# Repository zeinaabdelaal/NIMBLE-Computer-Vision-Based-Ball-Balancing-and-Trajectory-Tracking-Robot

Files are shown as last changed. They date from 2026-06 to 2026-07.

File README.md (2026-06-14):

# NIMBLE: Computer Vision Based Ball Balancing & Trajectory Tracking Robot

### System setup
<br>

f4afa68b-89f5-4ad4-aba0-d910d50fece1  

<br>
<br>

### Robot assembly
<br>

  

<br>
<br>

### Functional diagram 
<br>

ChatGPT Image May 22, 2026, 03_35_27 PM  

<br>
<br>

NIMBLE is a full-stack mechatronics system combining computer vision, embedded real-time control, inverse kinematics, and mechanical design into a single cohesive robot. A webcam detects the ball's position in real time, a Python application computes the positional error, and an STM32 microcontroller runs dual independent PID controllers that command two stepper motors to tilt a platform and keep the ball exactly where you want it.

Beyond simple balancing, the system supports trajectory tracking — the ball can follow a circle, a figure-eight, or any freehand path you sketch in the GUI.

Developed as a final project for Mechatronics Engineering (MCTR601) at the German University in Cairo.  
Supervised by Prof. Ayman A. El-Badawy.

This repository contains full documentation of the project and all CAD, lasercuting and code files.

Contributers:  
Zeina Abdelaal, Farah Abdelaal, Ahmed Shawki

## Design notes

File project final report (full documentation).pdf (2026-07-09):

## Mechatronics Engineering (MCTR601)

## Project Final Report

NIMBLE: Computer Vision Based Ball Balancing & Trajectory Tracking Robot

Name | ID | Lab Number
Zeina Abdelaal | 61-9589 | T-36
Ahmed Shawki | 61-32383 | T-35
Farah Abdelaal | 61-9586 | T-35

Supervised By:
Prof. Ayman A. El-Badawy

### Table of Contents

1. Project Description
2. Methodology
Mechanical design
Electrical design
3. Control
Modeling
Analysis
Controller Design
4. Programming
Computer Vision & GUI
STM32 Firmware (FreeRTOS)
5. Upgrades

### Project Description

Overview

The project is a vision-based ball balancing robot that keeps a ball at the center of a 2-DOF tilting platform using camera feedback and closed-loop control. The system combines computer vision, embedded control, inverse kinematics and mechanical design to continuously detect the ball’s position and adjust the platform angle to stabilize it. The challenge requires sensing the ball position in real time, computing corrective tilt angles, and actuating them fast enough to reject disturbances and maintain balance.

In addition to stabilization, the system also supports trajectory tracking, where the ball can be guided along predefined paths, such as a circular/infinity sign trajectory or a custom freehand sketch. This is achieved by dynamically updating the target position used to calculate the error, allowing the robot to not only balance the ball but also control its motion smoothly across the platform.

To enhance user interaction, the system includes a graphical user interface (GUI) for mode selection and trajectory drawing. It allows switching between different operating modes in real time, including center balancing mode, predefined trajectory tracking mode, and custom freehand drawing mode. Also enabling the user to sketch and edit the custom paths that the ball will follow on the platform.

How the System Works

A webcam captures images of the platform and detects the position of the ball (x,y) using image processing techniques (OpenCV running on a PC). The ball’s x and y positional errors relative to the desired target setpoint are then computed and sent to the STM32 through serial communication.

The STM32 runs two independent PID control algorithms that calculate how much the platform should tilt in the x and y directions to move the ball toward the target position. Based on this calculation, the microcontroller commands two stepper motors that adjust the platform angle.

The platform is supported using a central mount and 2 robotic arms that are built using custom 3D-printed links and mechanical components, creating a stable structure that allows controlled tilting in two axes.

Through this continuous loop — camera detection → position calculation → PID control → motor adjustment — the robot maintains the ball balanced at the center of the platform in real time.

Components Used

Sensor:
The primary sensor is the overhead USB webcam running at 30fps, which provides the (x, y) position of the ball through OpenCV-based image processing on the host PC.

Actuators:
Two Nema 17 stepper motors driven by their dedicated motor drivers (A4988); each motor controls tilt about one of the two platform axes (X & Y).

Microcontroller:

STM32 Blue Pill, acts as the real-time control unit, receives and parses the ball’s positional error transmitted over USART, executes the PID loops and generates the required stepper step/direction signals accordingly.

Communication Protocol:
A USB-to-TTL converter is used as the communication interface between the computer and the STM32. It transmits the ball’s positional error (x,y), over serial communication (USART) to the STM32.

Power Supply:

Two 12V 2A adaptors to power both motors.

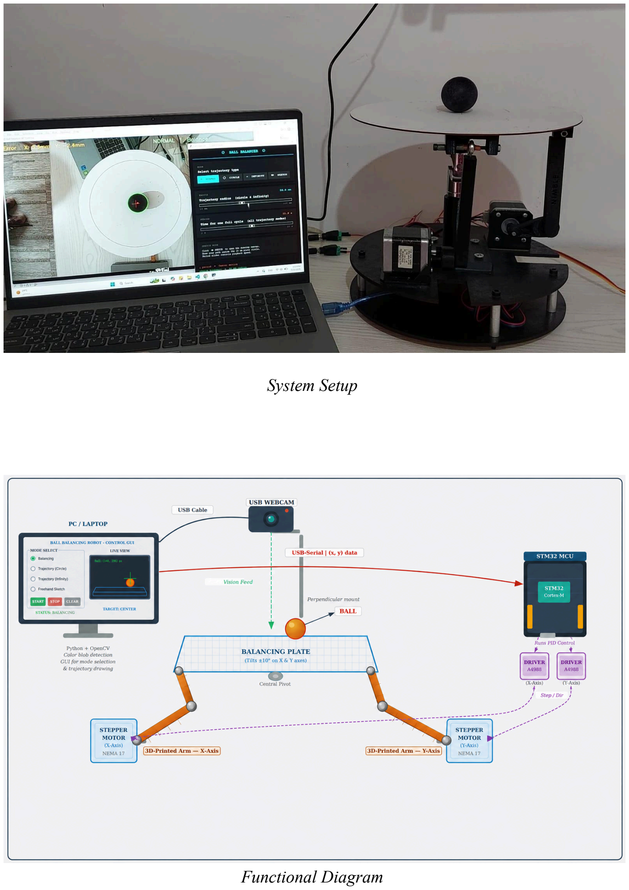
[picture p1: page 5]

System Setup

Functional Diagram

### Methodology

### 1. Mechanical design

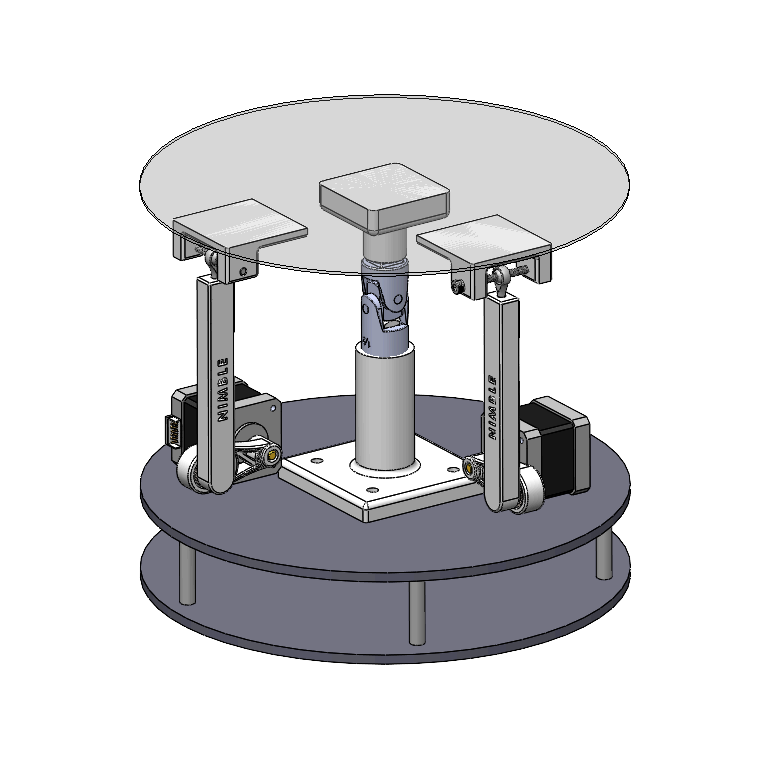
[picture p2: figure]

Robot Solidworks Assembly

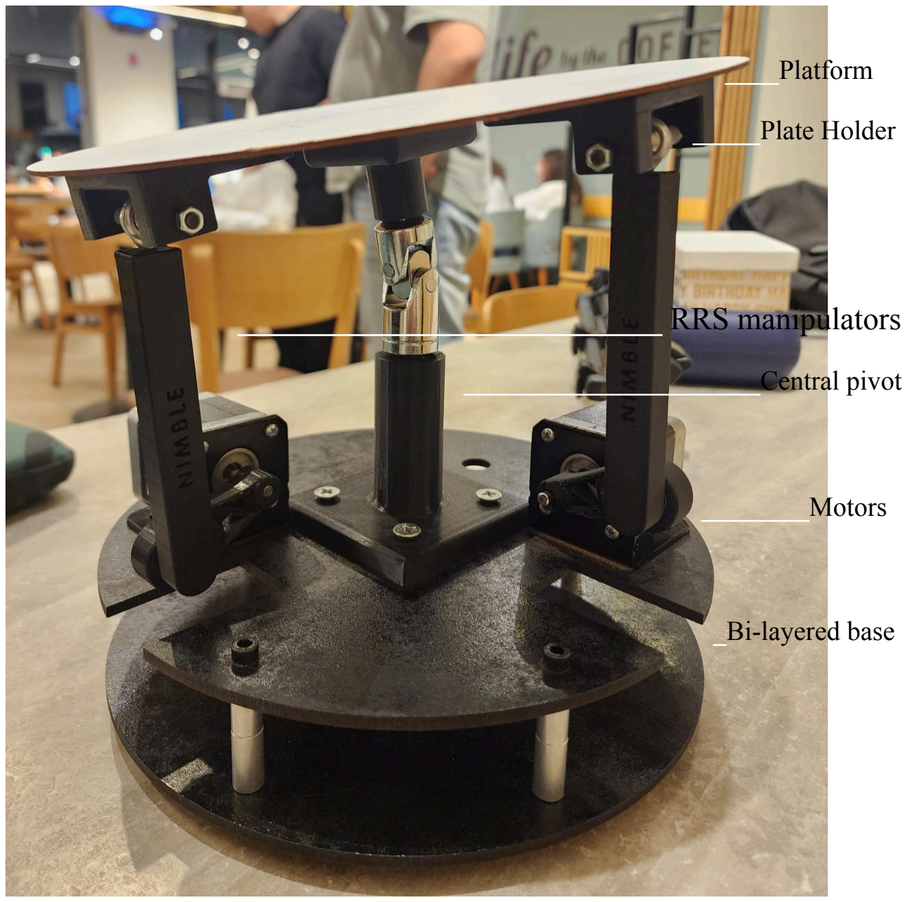
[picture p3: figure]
____Platform; _____Plate Holder; ______________________Central pivot; ________Motors; _Bi-layered base

___________________________ RRS manipulators

Real life Hardware with key components labelled

RRS Parallel Manipulators Design

We designed two RRS (Revolute-Revolute-Spherical) manipulators, each driven by a stepper motor to control platform tilt along one axis independently.

Each leg consists of two rigid links, a short arm and a long arm, connected in series by three joints

Starting from the base, the short arm is press-fitted directly onto the stepper motor shaft, forming the first actuated revolute joint - a clean rotational connection driven by the motor itself.

The long arm is then connected to the short arm via a 688ZZ bearing, forming the second revolute joint and allowing the long arm to rotate relative to the short arm about a single fixed axis.

At the top of the long arm, an M4 spherical joint connects to the plate holder, forming the terminal spherical joint. This allows rotation about multiple axes, accommodating the platform's combined tilt from both legs simultaneously. The plate holder is fastened via an M4 bolt, anchoring the platform while permitting free orientation in response to the manipulators' motion.

Together, the two decoupled RRS legs produce a 2-DOF tilting platform, with each leg independently controlling tilt about one axis.

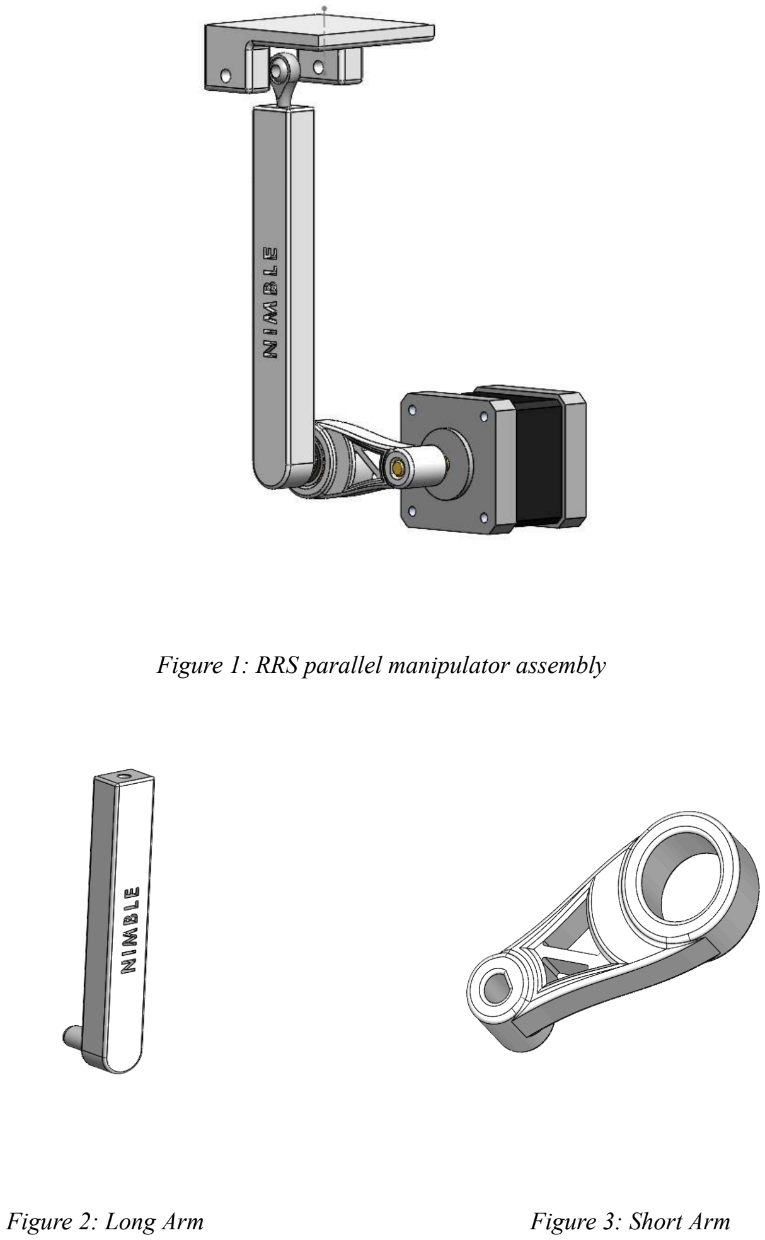
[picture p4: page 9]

Figure 1: RRS parallel manipulator assembly

Figure 2: Long Arm | Figure 3: Short Arm

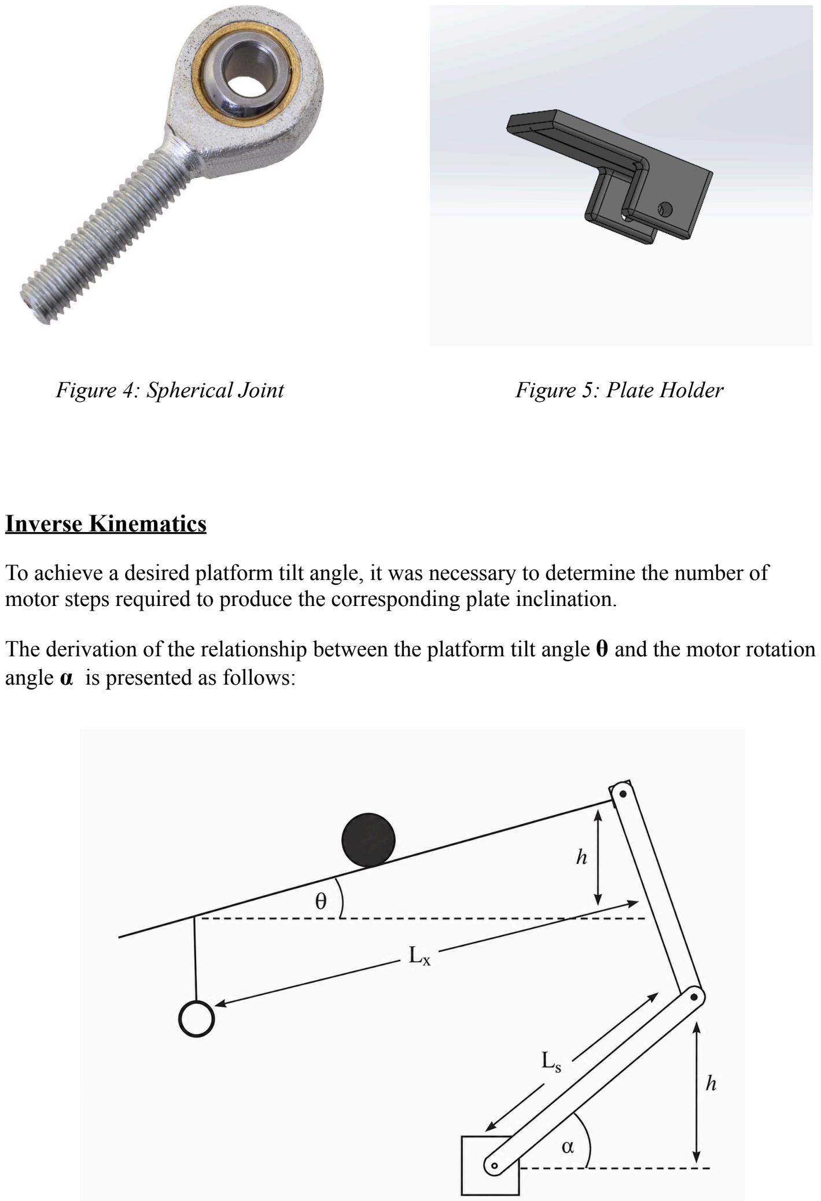
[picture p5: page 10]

Figure 4: Spherical Joint | Figure 5: Plate Holder

Inverse Kinematics

To achieve a desired platform tilt angle, it was necessary to determine the number of motor steps required to produce the corresponding plate inclination.

The derivation of the relationship between the platform tilt angle θ and the motor rotation angle α is presented as follows:

For simplicity and due to the small range of motion the long arm is assumed to be vertical throughout the motion. It therefore transmits vertical displacement directly and without distortion from the crank tip to the plate attachment point. This gives the central assumption:

h_{short arm} = h_{plate}

Left side — vertical height of the short arm tip above the motor pivot:

h_{short arm} = Ls sin(α)

Right side — vertical height of the plate attachment point, at distance Lx along the plate tilted by θ:

h_{plate} = Lx sin(θ)

Setting equal:

Ls sin(α) = Lx sin(θ)

Solving directly for the motor angle:

α=arcsin (Lx/Ls) sin(θ)

Linearized Form (Small Angle Approximation)

applying sinθ≈θ and sinα≈α:

α ≈ Lx/Ls θ

This reveals a constant linear gain (Lx/Ls) between plate angle and motor angle.

The two axes are fully decoupled — αx depends only on θx and αy depends only on θy

The linearized model is suitable for control design in the neighbourhood of the home (flat) position, which is the primary operating region of the manipulator.

For our parameters Lx=10.5cm, Ls=4cm, and ⅛ microstepping, the microsteps per degree of plate tilt is derived as follows.

A standard stepper motor has 200 full steps per revolution. With 1/8 microstepping this gives:

N=200×8=1600 microsteps/revolution

From the linearized IK, the mechanical gain is:

α/θ=Lx/Ls=10.5/4=2.625

meaning each degree of plate tilt demands 2.625° of motor rotation.The number of microsteps per degree of plate tilt is therefore:

microsteps per degree of plate tilt=(1600 * 2.625)/360 = 11.667 microsteps/°

Mount

To support the platform, we designed a central mount that attaches directly to the platform's center. The mount is split into two parts — a top and a bottom — with a Universal Joint sitting between them.

The Universal Joint acts as the core of the mount, linking the two halves while allowing the plate to rotate freely in any direction, giving it full 360° of rotational freedom.

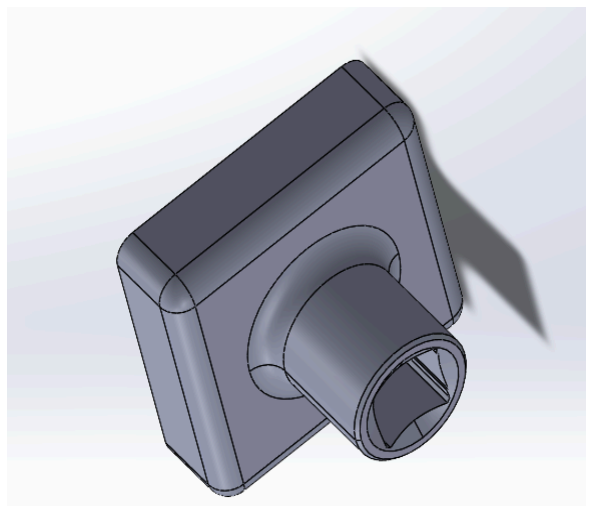
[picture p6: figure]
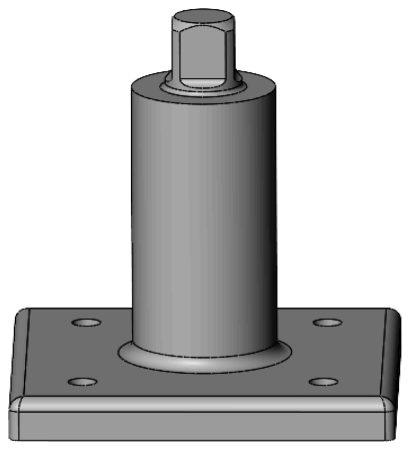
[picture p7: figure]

Figure 6: Top Mount | Figure 7: Bottom Mount

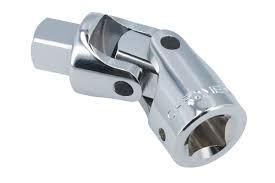
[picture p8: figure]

Figure 8: Universal Joint

Bi-Layered Base

The base consists of two 5mm MDF plates, laser cut for precision and separated by M5 spacers to create a structured two-tier frame.

The top platform houses the stepper motors and the central mount, keeping all mechanical components together in one layer. Cutouts are integrated into the platform, giving the arms the clearance they need to move freely without obstruction.

The bottom platform sits beneath, dedicated to the electrical components, keeping the wiring and electronics neatly separated from the mechanics above.

Platform

The platform was laser cut from 1.5 mm MDF with a diameter of 25 cm , with engravings on its underside marking the precise locations of the central pivot and plate holders. This ensured accurate positioning during assembly.

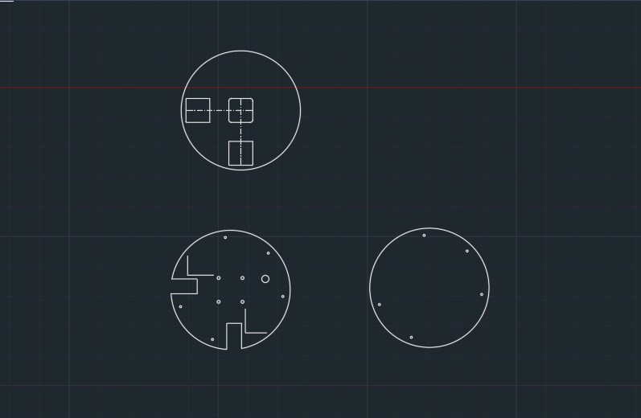
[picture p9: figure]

Figure 9: AutoCAD drawings for laser cutting

### 2.Electrical design

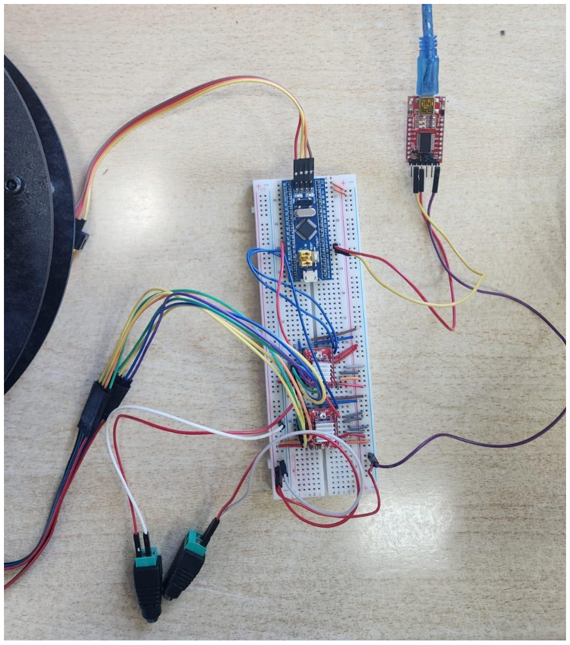
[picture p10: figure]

Components:

- SM32 Blue Pill & ST Link
- USB TTL Converter (To send X,Y positional errors to STM)
- Two A4988 Motor Drivers Connected to two Steppers
- Two 12V adapters (one for each stepper)

### Control

### 1.Modeling

### 1.1 Governing Equations — Derivation and Linearization

The ball balancing system is modelled by analysing the motion of a hollow thin-walled sphere rolling on a tilted plate. The following assumptions are applied:

Assumptions taken:

- The ball rolls without slipping on the plate surface
- Small angle approximation applies: sin(θ) ≈ θ for tilt angles ≤ 8°
- The plate is rigid, flat, and uniform
- Air resistance and rolling friction are neglected
- The two axes (X and Y) are mechanically decoupled and modelled independently
- The ball is a standard ping-pong ball modelled as a hollow thin-walled sphere with moment of inertia I = (2/3)mr²

Equations of motion:

Consider the ball of mass m and radius r rolling on the plate, which is tilted at angle θplate about one axis.

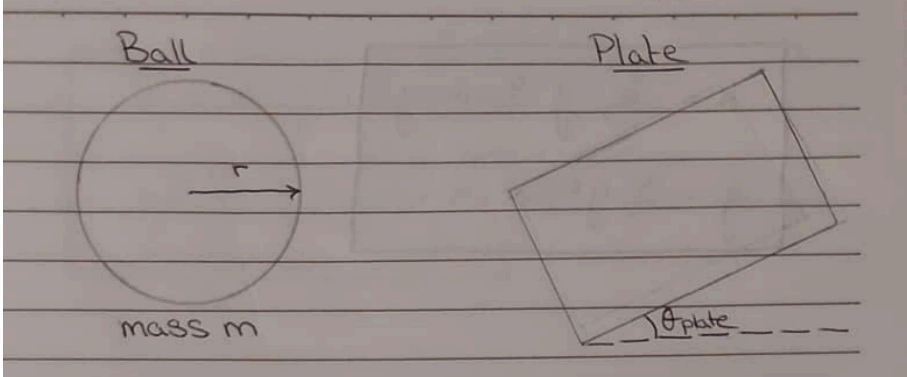
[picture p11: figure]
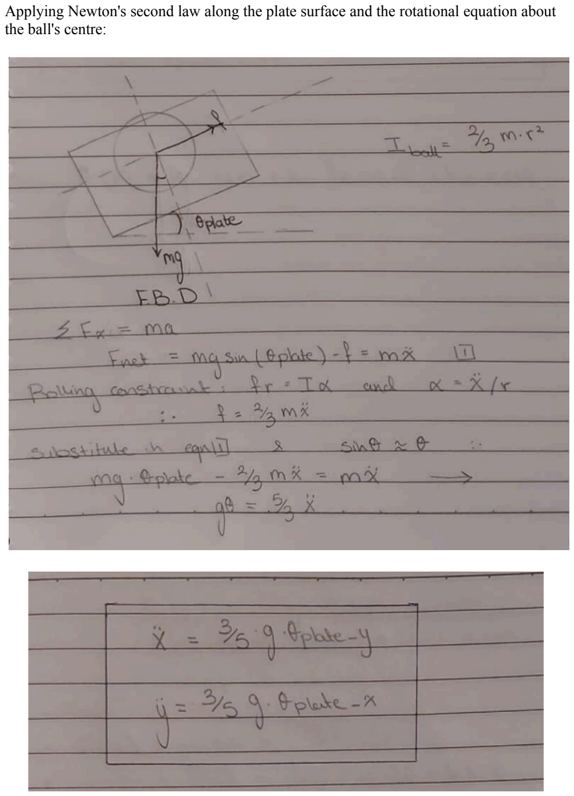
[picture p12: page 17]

Applying Newton's second law along the plate surface and the rotational equation about the ball's centre:

where g = 9.81 m/s² is gravitational acceleration, θplate_x and θplate_y are the plate tilt angles about the X and Y axes respectively, and (3/5) is the rolling inertia factor for a hollow thin-walled sphere. Note that this gives a plant gain of K = (3/5)g = 5.886 m/s²/rad.

### 1.2 Transfer Function Model

Open Loop Transfer Function

Taking the Laplace transform of the equation of motion for a single axis, treating θ_plate

as the control input and ball position x as the output:

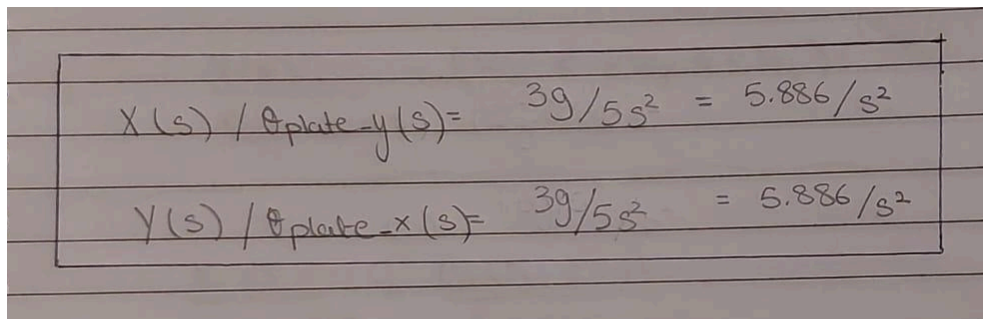
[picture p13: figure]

G(s) = X(s) / Θ_plate(s) = 5.886 /
s²

This is a double integrator plant. It is open-loop unstable with two poles at the origin, which is why active feedback control is required. Both axes share the same transfer function structure, so identical controllers are designed for each axis independently.

The stepper motor is modelled as a first-order lag with time constant τ = 0.0012 s (derived from the hardware step interval of 1200 µs from the C code):

M(s) = 1 / (0.0012s + 1)

The combined plant seen by the PID controller is:

P(s) = M(s) · G(s) = 5.886 / [s² · (0.0012s + 1)]

The open-loop transfer function is:

L_OL(s) = P(s) = 5.886 / [s² · (0.0012s + 1)]

PID Control Law

Each axis is controlled by an independent PID controller of the form:

where:

- e(t) = x_desired − x(t) for the X-axis, or e(t) = y_desired − y(t) for the Y-axis
- θ(t) is the commanded plate tilt angle sent to the stepper motor
- The output is saturated at ±8° matching the physical hardware limit from the STM32 C code

In transfer function form the PID controller is:

C(s) = Kp + Ki/s + Kd·s

Closed Loop Transfer Function

With the PID wrapped around it

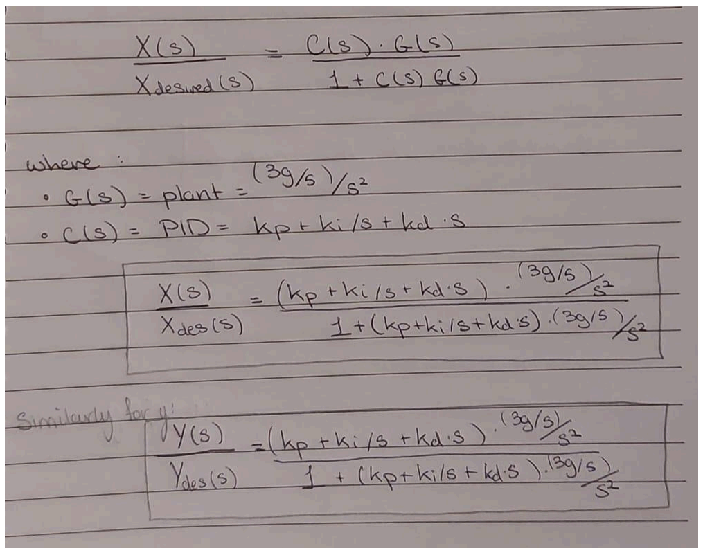
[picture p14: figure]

*Replace G(s) in the photo with P(s) (the combined plant)*

The closed-loop transfer function is:

T(s) = [C(s) · P(s)] / [1 + C(s) · P(s)]

T(s) = [Kp + Ki/s + Kd·s] · 5.886 / [s² · (0.0012s + 1)] -―――――――――――――――――――――――――――――――――――—----------1 + [Kp + Ki/s + Kd·s] · 5.886 / [s² · (0.0012s + 1)]

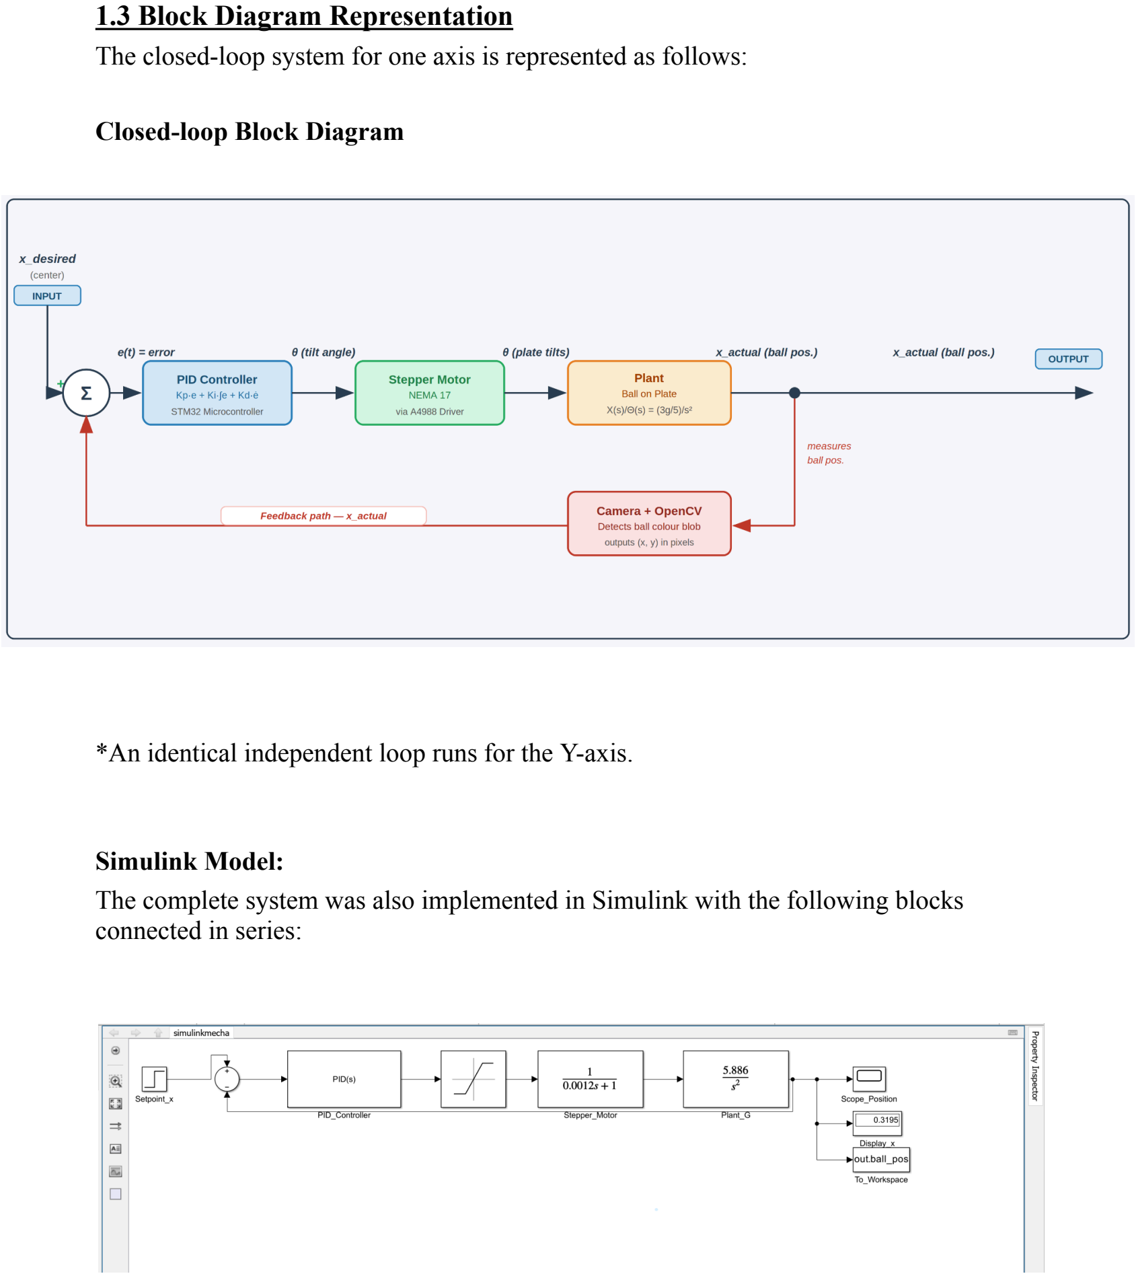
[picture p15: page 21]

### 1.3 Block Diagram Representation

The closed-loop system for one axis is represented as follows:

Closed-loop Block Diagram

*An identical independent loop runs for the Y-axis.

Simulink Model:
The complete system was also implemented in Simulink with the following blocks connected in series:

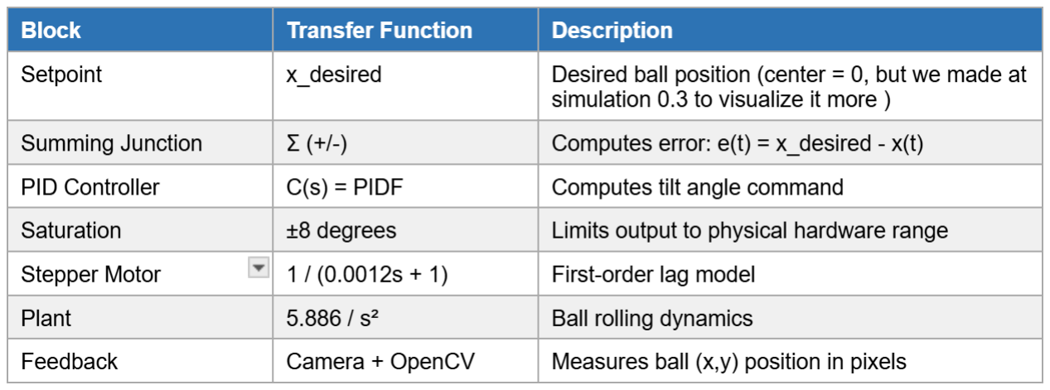
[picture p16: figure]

### 2. Analysis — Open Loop Response

Open-loop poles:

Pole | Location | Meaning
p₁, p₂ | s = 0 (double) | Double integrator — open-loop unstable
p₃ | s = −833 | Stepper motor lag

Open-loop analysis conclusions:

- Two poles at the origin confirm the system is open-loop unstable — any small tilt causes the ball to accelerate indefinitely away from center
- The Bode plot shows a −40 dB/decade slope at low frequencies, characteristic of a double integrator
- The open-loop step response shows ball position diverging to infinity, confirming that active closed-loop control is mandatory

### 3. Controller Design

### 3.1 Controller Design Steps

A PID controller (PID with derivative filter) was selected for the following reasons:

- The double integrator plant requires derivative action to introduce damping
- The integral term eliminates steady-state error as the ball settles at center

- Both X and Y axes use identical independent controllers due to mechanical decoupling

Design procedure:

Step 1 — Define the combined plant including motor dynamics:
P(s) = 5.886 / [s² · (0.0012s + 1)]
Step 2 — Apply MATLAB’s pidtune function targeting the design specifications: opts = pidtuneOptions('CrossoverFrequency', 1.5, 'PhaseMargin', 60) C = pidtune(P, 'PID', opts);
Step 3 — Extracted gains from pid tune output:
Gain | Value | Role
Kp | 0.070303 | Proportional — reacts to current error
Ki | 0.004885 | Integral — eliminates steady-state error
Kd | 0.248320 | Derivative — damps oscillation
Step 4 — Close the loop and verify stability margins and step response (shown in sections below).

### 3.2 Closed-Loop Simulations

The closed-loop system was simulated in MATLAB using the pidtune computed gains with a 33 ms sample time matching the STM32 hardware implementation.

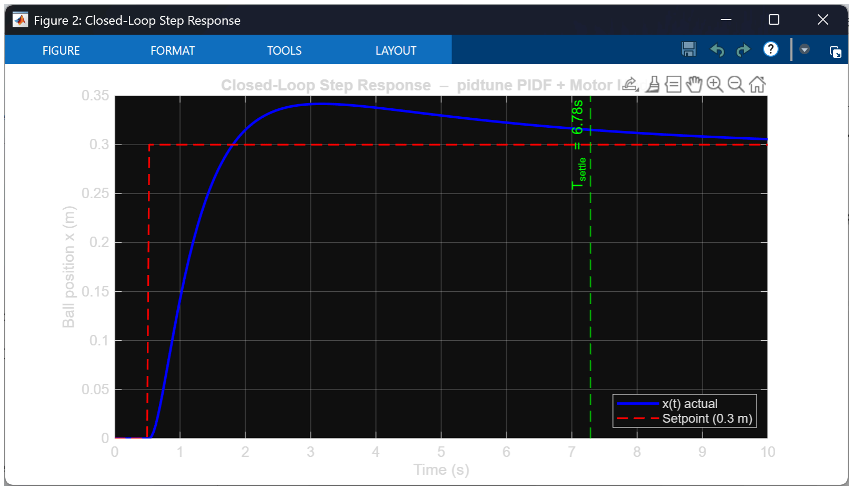
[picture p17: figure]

Closed Loop Step Response

Simulation conditions:
- Setpoint: ball moves from center (0 m) to 0.3 m at t = 0.5 s
- Simulation duration: 10 seconds
- Sample time: 33 ms (from STM32 C code default dt = 0.033 s)
- Output saturation: ±8° (from STM32 C code: output_max = 8.0)

The step response shows the ball position tracking the 0.3 m setpoint successfully. The system is stable with the following performance metrics:

Metric | Value
Settling Time | 6.78 s
Peak Overshoot | ~13% (peak ≈ 0.34 m)
Steady-State Error | ≈ 0 m (integral action eliminates offset)
Setpoint Reached | Yes — ball converges to 0.3 m

Stability Margins (from MATLAB margin function):

Margin | Achieved | Requirement | Status
Phase Margin | ≥ 60° | > 45° | ✓ Pass

Gain Margin | > 6 dB | > 6 dB | ✓ Pass

The closed-loop pole-zero map confirms all poles are located in the left half plane, verifying closed-loop stability.

Note on Comparison with Hardware Implementation
The pidtune computed gains (Kp = 0.070303, Ki = 0.004885, Kd = 0.248320) represent the theoretically optimal values for the specified design targets. The hardware-tuned gains implemented on the STM32 (Kp = 0.06, Ki = 0.02051, Kd = 0.02165) were arrived at through iterative physical testing on the actual robot. The difference between the two sets of gains reflects real-world factors not captured in the mathematical model, including mechanical friction, camera latency, and discrete step resolution of the NEMA 17 stepper motors.

### Programming

### 1. Computer Vision & GUI

The PC-side software is written in Python using OpenCV for real-time ball detection and Tkinter for the control GUI. It runs two concurrent threads — a CV loop processing camera frames at 30 FPS, and a GUI thread that lets the operator switch modes and tune parameters without interrupting tracking.

Computer Vision

Ball Detection Pipeline

Each frame from the USB webcam goes through the following steps:

1. Pre-processing

The raw BGR frame is first blurred with a 5×5 Gaussian kernel to suppress noise, then converted to the HSV colour space. HSV is used instead of BGR because it separates colour (hue) from lighting intensity (value), making the detection robust to changes in ambient light. A colour threshold mask is applied for the black ball:

lower_ball = np.array([0, 0, 0])
upper_ball = np.array([180, 255, 50])

This isolates all pixels with very low brightness (value < 50) regardless of hue, which corresponds to the black ball. The mask is then cleaned up with one erosion pass (removes noise specks) followed by two dilation passes (fills gaps in the ball's silhouette).

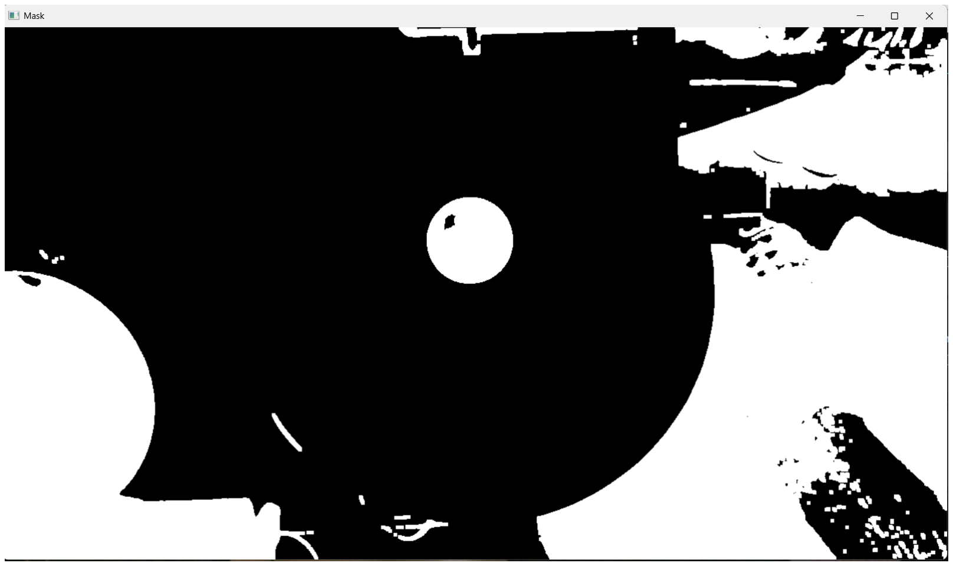
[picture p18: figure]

Masking

2. Contour detection and validation

OpenCV's findContours extracts all connected regions from the binary mask. Each contour is then filtered through two criteria to reject false positives:

- Radius bounds: the minimum enclosing circle must be between a pre-set minimum and maximum radius in pixels (selected based on the physical ball size and the camera height above the platform). This helps reject false detections such as tiny noise blobs or large shadow regions that do not correspond to the ball.

if r < MIN_RADIUS or r > MAX_RADIUS:
continue
- Circularity check: computed as (4π × area) / perimeter², which equals 1.0 for a perfect circle. Only contours with circularity ≥ 0.75 are accepted — rejects non-circular objects like cables or plate edges.

circ = (4 * np.pi * area) / (perim ** 2)
if circ < CIRCULARITY_THRESHOLD:
continue
3. Position extraction and filtering

After validating the contour, the largest valid contour is selected as the ball and its pixel position (ball_x, ball_y) is extracted. An exponential moving average (EMA filter) with α = 0.45 is then applied to reduce jitter from frame-to-frame noise:

x_smooth = 0.45 * ball_x + 0.55 * x_smooth
y_smooth = 0.45 * ball_y + 0.55 * y_smooth

The filtered position is then converted to millimetres relative to the frame centre using a calibrated mm per pixel scale factor (selected based on camera height from platform).

x_smooth_mm = (x_smooth - FRAME_CX) * MM_PER_PIXEL
y_smooth_mm = (y_smooth - FRAME_CY) * MM_PER_PIXEL
5. Error calculation and serial transmission

The smoothed ball coordinate position is compared against the current trajectory setpoint (centre for Normal mode, or a parametric path for Circle/Infinity/Sketch modes). The positional error in mm is multiplied by 10 to send as an integer over UART, avoiding floating point in the serial packet:

error_x_mm = x_smooth_mm - setpoint_x_mm
error_y_mm = y_smooth_mm - setpoint_y_mm
packet = f"<{int(error_x_mm * 10)},{int(error_y_mm * 10)}>\n" stm_serial.write(packet.encode('utf-8'))

The STM32 receives this packet via UART DMA, parses the <x,y> format, and feeds the error directly into the PID controller.

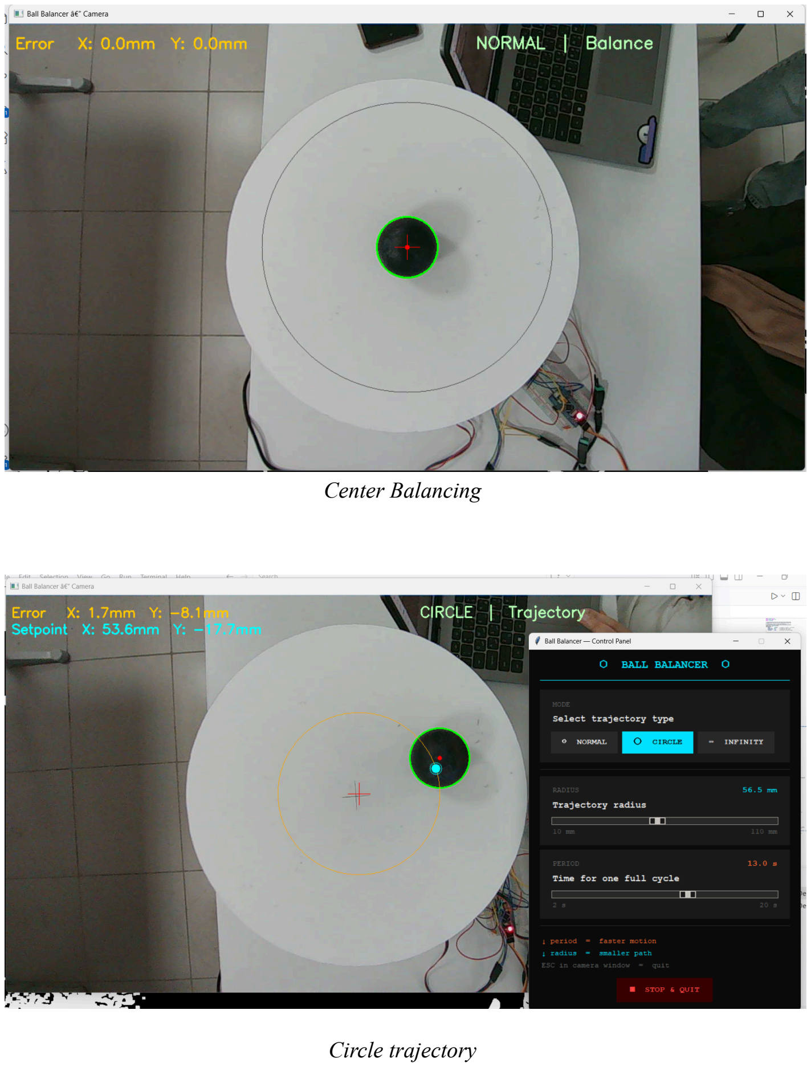
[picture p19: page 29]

Center Balancing

Circle trajectory

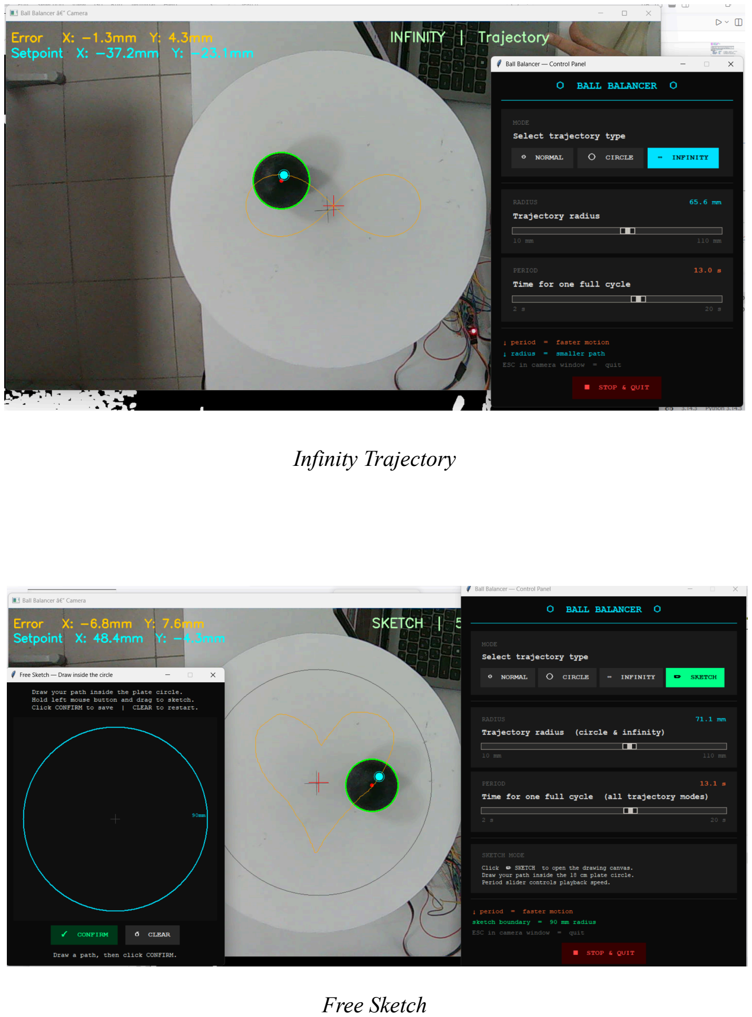
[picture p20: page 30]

Infinity Trajectory

Free Sketch

GUI

The GUI exposes four modes selectable at runtime without restarting the system:

Mode Setpoint behaviour

Normal Fixed at (0, 0) — ball balances at centre

Circle Parametric circle: x = R·cos(ωt), y = R·sin(ωt)

Infinity Lemniscate of Bernoulli (figure-of-eight curve)

Sketch User draws a freehand path on a canvas; ball follows it as a closed loop

The radius (10–110 mm) and period (2–20 s) for the circle and infinity trajectories are adjustable via sliders in real time. In Sketch mode, a drawing canvas appears allowing the user to sketch the desired path. The drawing canvas enforces a 90 mm boundary to reject any out-of-bounds point too close to the plate edge.

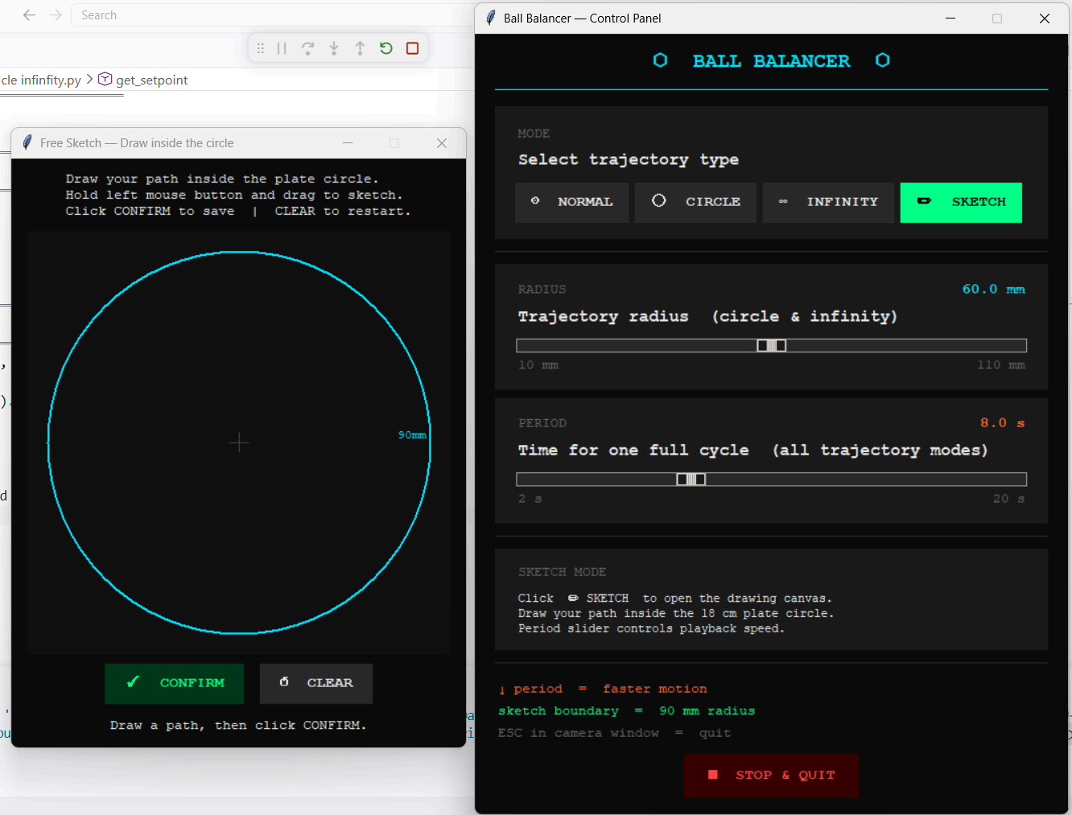
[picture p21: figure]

GUI

### STM32 Firmware (FreeRTOS)

The firmware runs on an STM32F103 at 72 MHz and is structured around FreeRTOS with two cooperative tasks. The PID computation and motor stepping are split into separate tasks that take turns running, while UART reception happens entirely in the background via DMA and an ISR.

System Clock & Timer

The MCU is clocked from an 8 MHz external crystal, multiplied by the PLL to 72 MHz. TIM2 is configured as a free-running microsecond counter:

TIM2->PSC = 71; // 72 MHz ÷ 72 = 1 MHz → 1 tick per µs

TIM2->ARR = 0xFFFFFFFF; // runs continuously, never resets

TIM2->CR1 |= TIM_CR1_CEN;

This 32-bit hardware timestamp is used for both measuring the actual time between PID updates (dt) and enforcing the minimum step interval between motor pulses, replacing all software delay loops for timing.

UART Reception (DMA + IDLE Interrupt)

USART1 runs at 115200 baud and receives packets from the PC in the format <x,y>. DMA Channel 5 is configured to transfer incoming bytes directly into rx_buffer in the background without any CPU involvement:

DMA1_Channel5->CPAR = (uint32_t)&(USART1->DR); // source: UART data register

DMA1_Channel5->CMAR = (uint32_t)rx_buffer; | // destination: rx_buffer
DMA1_Channel5->CNDTR = RX_BUFFER_SIZE; | // up to 32 bytes

The UART IDLE line interrupt fires when the bus goes quiet after a complete packet. The ISR reads how many bytes DMA transferred, null-terminates the buffer, searches for the < start character, and parses the two integers:

uint16_t bytes_received = RX_BUFFER_SIZE - DMA1_Channel5->CNDTR;

sscanf(start, "<%d,%d>", &current_x, &current_y);

new_data_flag = 1;

DMA is then immediately reset to receive the next packet. The ISR only sets a plain volatile flag — no FreeRTOS API calls are made, keeping interrupt latency minimal.

PID Controller

Two independent PID controllers run on the X and Y axes with tuned gains:

pid->kp = 0.06f;

pid->ki = 0.02051f;

pid->kd = 0.02165f;

The derivative term applies a 70/30 low-pass filter to smooth out noise from numerical differentiation:

float raw_derivative = (error - pid->prev_error) / dt;

float derivative = 0.7f * pid->prev_derivative + 0.3f * raw_derivative;

The integral is clamped to ±200 to prevent wind-up, and the output is clamped to ±8° — the physical tilt limit of the plate mechanism. The dt value is the actual elapsed time in seconds between consecutive received packets, measured from TIM2, so the controller adapts automatically if PC frame rate varies.

Stepper Motor Control

Each motor is driven by an A4988 driver over STEP and DIR GPIO pins on GPIOB. Update_Motors() is entirely non-blocking — it reads the current TIM2 timestamp and only pulses the STEP pin if enough time has elapsed since the last step:

if (diff != 0 &&

(now - motor_x.last_step_time_us) >= motor_x.min_step_interval_us) {

motor_x.step_port->BSRR = motor_x.step_pin_mask; // STEP high

delay_us(2); | // 2 µs pulse

motor_x.step_port->BRR = motor_x.step_pin_mask; // STEP low motor_x.current_steps += (diff > 0) ? 1 : -1;

motor_x.last_step_time_us = now;

}

The minimum step interval is 1200 µs, capping speed at ~833 steps/sec. The PID output angle is converted to a step target using 11.66 microsteps per degree of plate tilt (derived from the RRS inverse kinematics above). Direction is set from the sign of the remaining step error before each pulse.

FreeRTOS Task Structure

The firmware uses two tasks at equal priority (2), both calling taskYIELD() to cooperatively hand the CPU to each other:

vPIDTask (priority 2, 512-word stack) — polls new_data_flag on every iteration. When the flag is set by the ISR, it clears it, computes the actual dt, runs both PID controllers, and writes the new step targets to the motor structs. It then calls taskYIELD() to give the motor task a turn:

while (1) {

if (new_data_flag == 1) {

new_data_flag = 0;

// ... compute dt, run PID, update motor targets

}

taskYIELD();

}

vMotorTask (priority 2, 512-word stack) — calls Update_Motors() on every iteration to check whether either motor needs a step pulse, then yields:

while (1) {

Update_Motors();

taskYIELD();

}

Because both tasks are at the same priority and both call taskYIELD(), the FreeRTOS scheduler alternates between them on every yield — effectively running PID check and motor step in a round-robin loop. This mirrors the original bare-metal while(1) structure but separates the two concerns into distinct tasks. Neither task ever blocks or sleeps, since Update_Motors() requires continuous polling of TIM2 to maintain microsecond step timing.

### Upgrades

We later upgraded to a better quality webcam that also features a higher 60fps frame rate. This change required corresponding adjustments in the code to the PID control parameters, derivative filter configuration, and timing constraints to maintain stable and responsive tracking performance at the increased frame rate.

PID Gain Adjustments

The PID gains were recalibrated to account for the reduced time interval between frames. The proportional gain remained unchanged, as it is independent of frame rate. The integral and derivative gains were scaled accordingly.

pid->kp = 0.06f; | // no change (not affected by frame rate)
pid->ki =0.0229712f; | // 1.12 times the 30fps value
pid->kd = 0.01786129f; | // approx 0.825 times the 30fps value

Derivative Filter Update

The smoothing coefficient was adjusted from 70/30 to 80/20, applying stronger filtering to the derivative term to suppress the increased noise sensitivity inherent at shorter sampling intervals.

float derivative = 0.8f * pid->prev_derivative + 0.2f * raw_derivative;

Timing Constraint Adjustment

The upper bound on the time step dt was updated to reflect the expected inter-frame interval at 60 FPS (≈ 16.7 ms)

if (dt > 0.1f || dt <= 0.0f) dt = 0.0167f;

Camera Configuration (OpenCV)

The capture device was explicitly configured to operate at 60 FPS within the computer vision pipeline:

cap.set(cv2.CAP_PROP_FPS, 60)

Note: The actual achieved frame rate is subject to hardware capability. It is recommended to verify the effective frame rate at runtime by printing it in the terminal and confirming it reads 60 FPS.

*All other code remains unchanged from the original 30 FPS implementation.*

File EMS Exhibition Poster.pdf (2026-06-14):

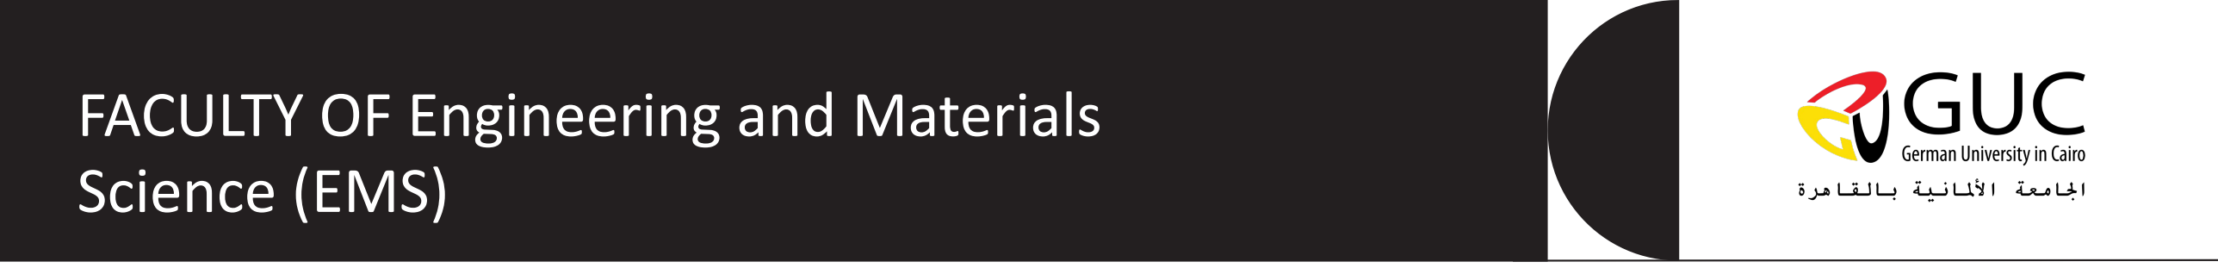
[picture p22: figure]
FACULTY OF Engineering and Materials Science (EMS)

Designed by
Ahmed Shawki, Farah Abdelaal, Zeina Abdelaal

Supervised by
Prof. Ayman A. El-Badawy

# NIMBLE: Computer Vision Based Ball Balancing & Trajectory Tracking Robot

Computer Vision
Using a 30 fps webcam each frame is processed in Python using OpenCV — converted to HSV color space, thresholded to isolate the black ball, and filtered using circularity and radius checks to reject false detections. An exponential moving average filter then smooths the ball's pixel position frame-to-frame, which is compared against the target setpoint to compute the positional error

Overview
NIMBLE is a vision-based ball balancing robot that keeps a ball at the center of a 2-DOF tilting platform using camera feedback and closed-loop control. The system combines computer vision, embedded control, inverse kinematics and mechanical design to continuously detect the ball's position and adjust the platform angle to stabilize it. In addition to stabilization, the system also supports trajectory tracking, where the ball can be guided along predefined paths, such as a circular/infinity sign trajectory or a custom freehand sketch.

Methodology
An overhead webcam captures the ball's positional error using OpenCV image processing and transmits it to an STM32 microcontroller. The STM32 runs two independent PID control loops — one per axis — calculating the required tilt angles. These angles are executed by two NEMA 17 stepper motors, which physically tilt the plate and close the feedback loop.
Trajectory Tracking | Control System Design
| The system models a ping-pong ball on a tilted plate as a double integrator plant G(s) = 5.886/s², making it open-loop unstable. A PID controller stabilizes each axis independently. MATLAB's pidtune achieved ≥60° phase margin and ~6.78s settling time in simulation.

Robot Assembly

Setup

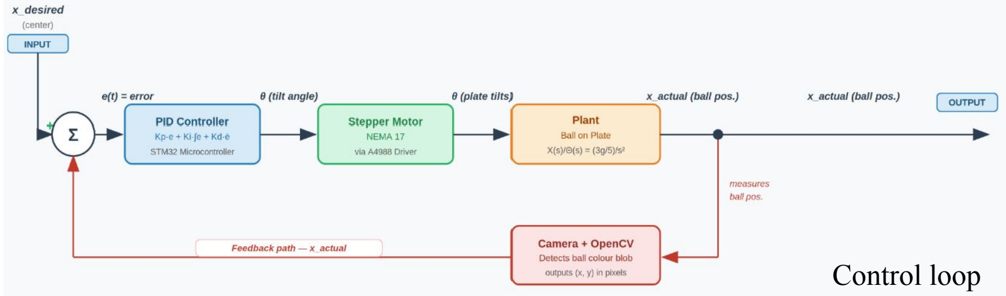
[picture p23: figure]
Control loop

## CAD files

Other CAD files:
lasercut file.dwg
